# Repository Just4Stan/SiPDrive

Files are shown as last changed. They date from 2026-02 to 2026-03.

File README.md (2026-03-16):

# SiPDrive (Work In Progress, Status: Ordering first hardware)

**Compact Field-Oriented Control (FOC) firmware and hardware for QDD actuators**

SiPDrive is an open-source motor controller built around the STSPIN32G4 System-in-Package, MT6701 magnetic encoder, and CAN-FD communication. It targets compact quasi-direct-drive (QDD) actuator applications with torque, position, and speed control.

<p align="center">
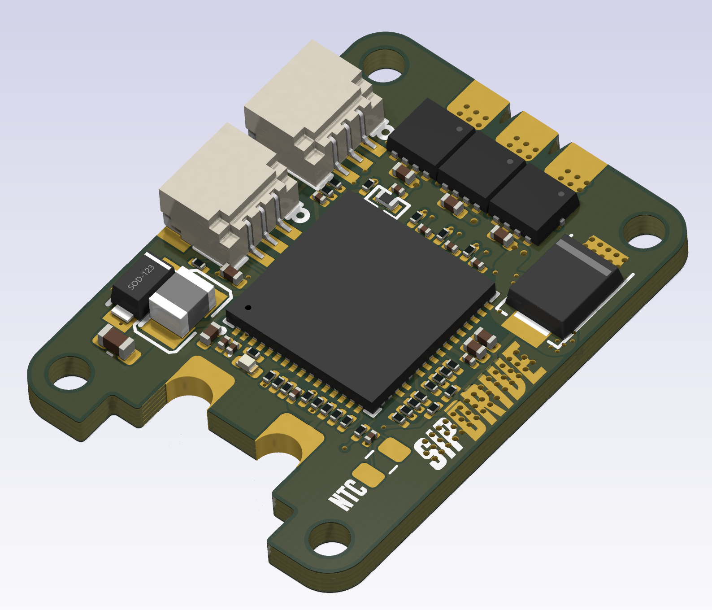
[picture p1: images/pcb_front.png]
SiPDrive PCB front
  
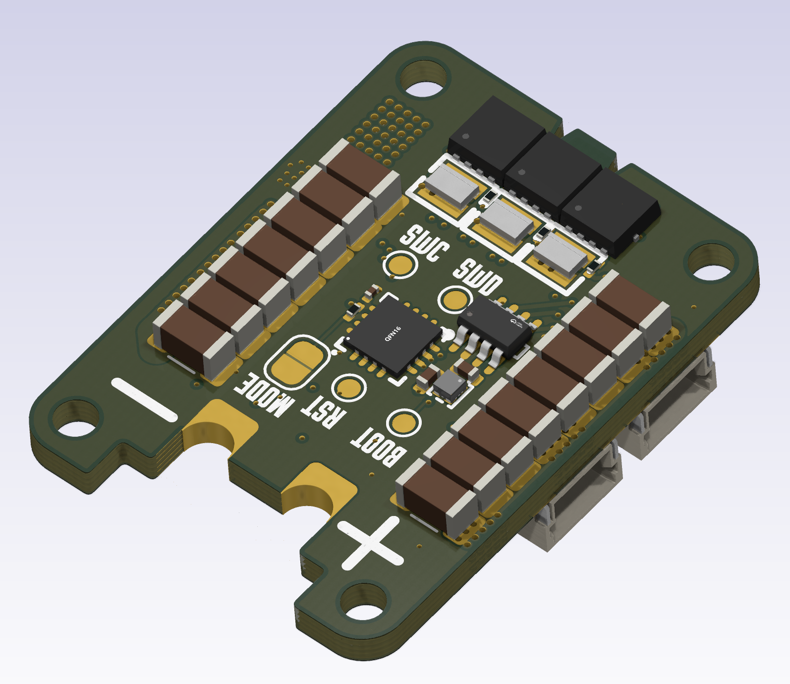
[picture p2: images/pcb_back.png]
SiPDrive PCB back
  
</p>

| | Status |
|---|---|
| **Build** | Compiles (macOS ARM GCC 15.2.0) |
| **Hardware** | PCB designed, ordering assembled from JLCPCB |
| **Firmware** | ~3,100 LOC, 11 KB Flash (8.4%), 13 KB RAM (59%) |
| **License** | CC BY-NC 4.0 |

### Key Features

- 40 kHz FOC current loop with hardware CORDIC acceleration
- CAN-FD command/telemetry (1 Mbps nominal, 5 Mbps data)
- Current and position control modes
- 14-bit magnetic encoder (MT6701 SSI/ABZ selectable via solder jumper)
- On-device encoder calibration with 128-entry compensation table
- Persistent configuration in flash (CRC32 protected)
- Thermal derating and fault protection (board + stator NTC)
- Space Vector PWM (SVPWM) with configurable duty limits

---

## Quick Start

### Prerequisites

```bash
# macOS
brew install arm-none-eabi-gcc cmake
```

### Fetch Dependencies

```bash
cd external
git clone --depth 1 --branch 5.9.0 https://github.com/ARM-software/CMSIS_5.git CMSIS
git clone --depth 1 https://github.com/STMicroelectronics/cmsis_device_g4.git
```

### Build

```bash
cmake -B build \
  -DCMAKE_TOOLCHAIN_FILE=cmake/arm-none-eabi-gcc.cmake \
  -DCMAKE_BUILD_TYPE=Release \
  -DSIPDRIVE_CMSIS_CORE_DIR=external/CMSIS/CMSIS/Core/Include \
  -DSIPDRIVE_STM32G4_DEVICE_DIR=external/cmsis_device_g4

cmake --build build
```

Outputs: `build/SiPDrive.elf`, `.bin`, `.hex`, `.map`

### Flash

```bash
# ST-LINK (recommended)
st-flash write build/SiPDrive.bin 0x08000000

# OpenOCD
openocd -f interface/stlink.cfg -f target/stm32g4x.cfg \
  -c "program build/SiPDrive.elf verify reset exit"
```

---

## Repository Layout

```
SiPDrive/
├── src/                    Firmware source (~3,100 LOC)
├── hw/SiPDrive/            KiCad schematic, PCB, datasheets
├── cmake/                  Toolchain configuration
├── link/                   Linker script (STM32G431)
└── external/               CMSIS dependencies (not vendored)
```

---

<details>
<summary><h2>Hardware Architecture</h2></summary>

### Core Components

**STSPIN32G4 (U1)** - System-in-Package containing:
- STM32G431CBU6 (Cortex-M4F @ 170 MHz)
- Integrated 3-phase gate driver
- Buck converter for MCU power
- 3x operational amplifiers for current sensing
- Memory: 128 KB Flash, 22 KB SRAM + 10 KB CCM RAM

**MT6701 (U2)** - 14-bit magnetic angle sensor
- SSI (default, MODE=HIGH) or ABZ mode (JP1 solder jumper to GND)
- PB7=DO/A, PB6=CLK/B, PB4=CSN/Z

**TCAN1057A (U3)** - CAN-FD transceiver (up to 5 Mbps)

### Pin Assignments

| Peripheral | Function | Pins |
|---|---|---|
| TIM1 | 3-phase PWM (internal to STSPIN32G4 gate driver) | GHS/GLS via 20R gate resistors |
| TIM4 | QEI encoder (ABZ mode) or SPI (SSI mode) | PB7=DO/A, PB6=CLK/B, PB4=CSN/Z |
| OPAMP1 | Phase U current (Ia) | PA1(+), PA3(-), PA2(out) |
| OPAMP2 | Phase W current (Ic) | PA7(+), PC5(-), PA6(out) |
| OPAMP3 | Phase V current (Ib) | PB0(+), PB2(-), PB1(out) |
| ADC1/2 | Vbus, board NTC, stator NTC | PC0 (IN6), PC1 (IN7), PC2 (IN8) |
| FDCAN1 | CAN-FD | PA11=RX, PA12=TX, PA10=TCAN standby |
| I2C3 | STSPIN32G4 gate driver config | Internal SiP bus (no external pins) |
| CORDIC | Hardware sin/cos | - |

### Current Sensing

3-shunt topology with biased differential OPAMPs (EVL reference design):
- **Shunts**: 3x 2 mR (SME08A1FR002T, 0805 1W) on low-side MOSFET sources
- **OPAMP gain**: 10x (Rf=15k / Rin=1.5k), mid-rail bias via 30k/30k divider on OPAMP+ nodes
- **MOSFETs**: 6x CMSA015N06 with 20R gate resistors

### Hardware Constraints

- **128 KB Flash** total - code size must be minimized
- **SCREF overcurrent**: 0.30V threshold via 100k/10k divider (~150A trip with 2 mR shunts)
- **MT6701 MODE**: R6 10k pullup = SSI default, JP1 jumper to GND for ABZ mode
- **Stator NTC (R14)**: DNP solder pad for external thermistor

### KiCad Project

- Schematic: `hw/SiPDrive/SiPDrive.kicad_sch`
- PCB: `hw/SiPDrive/SiPDrive.kicad_pcb`
- Netlist: `hw/SiPDrive/SiPDrive.net`
- Custom libraries: `hw/SiPDrive/kicad/libs/`
- Production outputs: `hw/SiPDrive/production/`

</details>

<details>
<summary><h2>Firmware Architecture</h2></summary>

### Source Layout

| File | Purpose |
|---|---|
| `main.cc` | Main loop, CAN protocol, control loop ISR |
| `config.h` | Compile-time constants |
| `foc_core.{h,cc}` | Clarke/Park transforms, PI current control |
| `position_control.{h,cc}` | Position/velocity PID |
| `calibration.{h,cc}` | Encoder calibration state machine |
| `hal_tim1_pwm.{h,cc}` | TIM1 PWM + 40 kHz ISR |
| `hal_adc_opamp.{h,cc}` | ADC + OPAMP (injected + regular) |
| `hal_qei.{h,cc}` | Quadrature encoder (TIM3/4) |
| `hal_fdcan.{h,cc}` | CAN-FD driver |
| `hal_i2c3_stspin.{h,cc}` | Gate driver I2C config |
| `hal_flash.{h,cc}` | Flash read/write |
| `hal_gpio.{h,cc}` | GPIO utilities |
| `thermal.{h,cc}` | NTC monitoring + derating |
| `persistent_config.{h,cc}` | Flash config (CRC protected) |
| `runtime_support.cc` | Math/string fallbacks (no newlib) |

### Startup Sequence

1. Enable DWT cycle counter
2. Load persistent config from flash (or defaults)
3. Init STSPIN32G4 gate driver via I2C3
4. Init TIM1 PWM (40 kHz) + register ISR
5. Init ADC + OPAMP, calibrate current offsets (1024 samples)
6. Init QEI encoder interface
7. Init FDCAN
8. Apply config (PID gains, thermal limits, calibration)
9. Enable TIM1 and power stage
10. Enter main loop

### Main Loop (~1 kHz)

- Service regular ADC (Vbus, NTC temperatures)
- Update thermal protection
- Handle CAN-FD RX (command frames)
- Run calibration state machine (if active)
- Send telemetry (10 Hz heartbeat)
- Sleep via `__WFI()`

### Control Loop ISR (40 kHz)

1. Check fault conditions (hardware, thermal)
2. Sample encoder position/velocity
3. Read injected ADC (Ia, Ib)
4. Compute Id/Iq command (current mode: direct, position mode: PID cascade)
5. Apply thermal derating
6. FOC pipeline: Clarke -> Park (CORDIC) -> PI controllers -> inverse Park -> SVPWM
7. Update TIM1 duty cycles
8. Queue telemetry if heartbeat due

### HAL Abstraction

All hardware access is through `hal_*` modules. When modifying HAL code, ensure ISR timing is preserved. Use `SIPDRIVE_DEBUG_TIMING=ON` to profile via GPIO.

</details>

<details>
<summary><h2>FOC Algorithm</h2></summary>

Implementation in `foc_core.cc`:

**Clarke Transform** (3-shunt, using Ia and Ib; Ic available for validation):
```
i_alpha = ia
i_beta  = (ia + 2*ib) / sqrt(3)
```

**Park Transform** (using CORDIC hardware, Q1.31 format):
```
id =  cos(theta)*i_alpha + sin(theta)*i_beta
iq = -sin(theta)*i_alpha + cos(theta)*i_beta
```

**PI Current Controllers** (independent Id/Iq):
- Default Kp = 0.30, Ki = 200.0
- Anti-windup: integrator clamped to +/-Vbus/2

**SVPWM**: Common-mode voltage centering, duty range 2%-98%

</details>

<details>
<summary><h2>Control Modes</h2></summary>

### Current Mode (`Mode::kCurrent`)
- Direct Id/Iq control
- 4-byte CAN frame: `[Id_mA, Iq_mA]` (int16 LE)

### Position Mode (`Mode::kPosition`)
- Cascaded PID: position -> velocity -> Iq
- Gains scaled by kp_scale, kd_scale (0.0-1.0)
- 16-byte CAN-FD frame (see protocol section)

</details>

<details>
<summary><h2>CAN-FD Protocol</h2></summary>

### Command Frame (default ID: 0x101)

**4-byte legacy** (current control):

| Byte | Field | Type |
|---|---|---|
| 0-1 | Id | int16 mA, LE |
| 2-3 | Iq | int16 mA, LE |
| 4 | Flags | bit0=clear fault, bit1=start cal |

**16-byte extended** (position/current):

| Byte | Field | Type |
|---|---|---|
| 0-3 | Position | float32 rad, LE (NaN = no position loop) |
| 4-7 | Velocity | float32 rad/s, LE |
| 8-9 | Max torque | int16 mA, LE |
| 10-11 | kp_scale | uint16, 0-32767 maps to 0.0-1.0 |
| 12-13 | kd_scale | uint16, 0-32767 maps to 0.0-1.0 |
| 14 | Flags | same as legacy |
| 15 | Mode | 0=current, 1=position |

### Telemetry Frame (default ID: 0x181, 24 bytes, 10 Hz)

| Byte | Field | Type |
|---|---|---|
| 0-3 | Position | float32 rad, LE |
| 4-7 | Velocity | float32 rad/s, LE |
| 8-9 | Iq measured | int16 mA, LE |
| 10-11 | Id measured | int16 mA, LE |
| 12-13 | Vbus | uint16 mV, LE |
| 14-15 | Board temp | int16, 0.01 C, LE |
| 16-17 | Stator temp | int16, 0.01 C, LE |
| 18 | Fault flags | bit0=gate, bit1=CAN, bit2=thermal |
| 19 | Mode | current mode enum |
| 20-23 | Reserved | - |

</details>

<details>
<summary><h2>Configuration</h2></summary>

### Persistent Configuration

Stored in flash (last page), CRC32 protected, magic `0x4D4D4347`.

Fields: motor pole pairs, current limit, PID gains (position Kp/Ki/Kd, velocity Kp/Ki), velocity limit, thermal thresholds, CAN IDs, encoder calibration (offset + 128-entry table).

### Compile-Time Configuration (`config.h`)

| Parameter | Default | Description |
|---|---|---|
| `SIPDRIVE_SYS_CLOCK_HZ` | 170 MHz | PLL or 16 MHz HSI |
| `SIPDRIVE_CONTROL_LOOP_HZ` | 40000 | Control loop rate |
| `SIPDRIVE_PWM_FREQUENCY_HZ` | 40000 | PWM frequency |
| `SIPDRIVE_TIM1_DEADTIME_NS` | 250 | Gate driver deadtime |
| `SIPDRIVE_ENCODER_CPR` | 16384 | MT6701 14-bit |

### CMake Options

| Option | Default | Description |
|---|---|---|
| `SIPDRIVE_USE_PLL170` | ON | 170 MHz PLL clock |
| `SIPDRIVE_USE_BKIN` | OFF | TIM1 break input (PE15) |
| `SIPDRIVE_DEBUG_TIMING` | OFF | GPIO ISR profiling |

### Adding a New Parameter

1. Add CMake cache variable in `CMakeLists.txt`
2. Add `target_compile_definitions` pass-through
3. Add `#ifndef` fallback + `constexpr` in `config.h`

</details>

<details>
<summary><h2>Encoder Calibration</h2></summary>

Implemented in `calibration.cc`. Compensates encoder non-linearity and determines electrical angle offset.

1. **Forward sweep**: Drive motor with fixed d-axis voltage, sweep electrical angle 0 to 2pi, record encoder error
2. **Reverse sweep**: Repeat in opposite direction to average out cogging torque
3. **Compute table**: 128-entry lookup (encoder angle to correction)
4. **Save to flash**: Electrical offset + compensation table persisted

Trigger calibration via CAN command flag bit 1. Motor must be free to rotate.

</details>

<details>
<summary><h2>Thermal Protection</h2></summary>

Two-level protection per sensor (board NTC, stator NTC):

1. **Warning**: Linear current derating from (fault_temp - margin) to fault_temp
2. **Fault**: Power stage disabled above fault threshold

Defaults: board 120 C fault / 25 C margin, stator 150 C fault / 25 C margin.

NTC thermistors read via ADC at ~1 kHz with piecewise lookup-table interpolation.

</details>

<details>
<summary><h2>Build System Details</h2></summary>

### Toolchain

- ARM GCC 15.2.0 (`arm-none-eabi-gcc`)
- CMake >= 3.20
- Cortex-M4F hard-float configuration

### Dependencies

| Dependency | Location | Source |
|---|---|---|
| CMSIS Core 5.9.0 | `external/CMSIS/` | github.com/ARM-software/CMSIS_5 |
| STM32G4 Device | `external/cmsis_device_g4/` | github.com/STMicroelectronics/cmsis_device_g4 |

### Custom Runtime (`runtime_support.cc`)

Provides `sinf`, `cosf`, `sqrtf`, `fmodf`, `atan2f`, `fabsf`, `memset`, `memcpy`, `memmove`, `memcmp`. Needed because Homebrew ARM toolchain lacks newlib. Uses Taylor series approximations - accuracy ~0.001 for trig functions.

### Memory Layout (linker script: `link/stm32g431vb.ld`)

| Region | Address | Size |
|---|---|---|
| FLASH | 0x08000000 | 128 KB |
| RAM | 0x20000000 | 22 KB |
| CCMRAM | 0x10000000 | 10 KB |

### Current Memory Usage

```
FLASH    11,056 B / 128 KB   8.44%
RAM      13,344 B /  22 KB  59.23%
CCM RAM   8,192 B /  10 KB  80.00%
```

Stack is 4 KB, not yet profiled on hardware.

### Verification

```bash
arm-none-eabi-size -A build/SiPDrive.elf
arm-none-eabi-nm -C -S --size-sort build/SiPDrive.elf
```

### Known Build Issues

1. **FDCAN RXESC/TXESC** registers missing from STM32G431 CMSIS headers (lines commented out in `hal_fdcan.cc`)
2. **Math approximations** - Taylor series trig may need improvement for production
3. **No unit tests** - FOC math validated by inspection only

### Datasheets

Component datasheets are in `hw/SiPDrive/datasheets/`. The STM32G4 reference manual (RM0440, ~37 MB) is gitignored to keep clone size down. Download it directly from [ST](https://www.st.com/resource/en/reference_manual/rm0440-stm32g4-series-advanced-armbased-32bit-mcus-stmicroelectronics.pdf) and place at:
```
hw/SiPDrive/datasheets/rm0440-stm32g4-series-advanced-armbased-32bit-mcus-stmicroelectronics.pdf
```

</details>

<details>
<summary><h2>Bring-Up Workflow</h2></summary>

### Pre-Flight Checklist

- [ ] Motor pole pairs match `config.h` (`kMotorPolePairs = 7`)
- [ ] Encoder CPR correct (`kEncoderCountsPerRev = 16384`)
- [ ] Shunt value correct (`kShuntOhm = 0.002`)
- [ ] OPAMP gain matches hardware (`kOpampGain = 10.0`)
- [ ] Current limits set appropriately
- [ ] Bus voltage safe (`kBusVoltageV = 24.0f`)
- [ ] Thermal limits reviewed

### Step-by-Step

1. **Bench setup**: Current-limited supply, motor free, ST-LINK connected, CAN-FD adapter with 120 ohm termination

2. **Flash**: `st-flash write build/SiPDrive.bin 0x08000000`

3. **CAN-FD host setup**:
   ```bash
   sudo ip link set can0 down
   sudo ip link set can0 type can bitrate 1000000 dbitrate 5000000 fd on
   sudo ip link set can0 up
   ```

4. **Verify telemetry**: `candump can0,181:7FF`

5. **Low-current test** (Id=0, Iq=1000 mA):
   ```bash
   cansend can0 101##10000E803
   ```

6. **Position mode**: Only after current control is validated. Start with small torque limits and low gains.

7. **Calibration**: Set command flag bit 1 in CAN frame.

8. **Validate**: PWM outputs, current polarity, encoder direction, thermal/fault behavior.

### Safety Warnings

- Code is **untested** - expect bugs
- Current sensing polarity is **unknown** until verified
- Electrical angle offset requires **calibration**
- No hardware current limit - **software only**
- Stack usage is **unprofiled**

</details>

<details>
<summary><h2>Schematic Audit (2026-02-14)</h2></summary>

Validated against STSPIN32G4, EVLSPIN32G4-ACT, MT6701, and TCAN1057A datasheets.

**Verdict**: Schematic is ready for PCB layout.

### Current Sensing (validated)

3-shunt biased differential topology matching EVLSPIN32G4-ACT reference:
- 30k/30k bias dividers on OPAMP+ nodes (PA1, PA7, PB0) - provides 1.65V mid-rail DC bias
- 1.5k input resistors from shunt nodes to OPAMP+ inputs
- 15k/1.5k feedback gives 10x differential gain
- 2 mR shunts (SME08A1FR002T, 0805 1W) — full-scale ±82.5A, ~40 mA/LSB resolution

### SCREF Divider (valid)

R15=100k / R37=10k / C30=33n gives VSCREF = 0.300 V. Within STSPIN32G4 valid range (0.2 V to 2.55 V). Estimated trip current ~120 A for 2.5 mohm RDS(on).

### 6S Battery Divider (valid)

R10=100k / R9=10k gives gain 11. At 25.2 V max: Vadc = 2.29 V (within 3.3 V range).

### Inter-IC Validation

| Connection | Status |
|---|---|
| U1 PB7 <-> U2 A (encoder) | Pass |
| U1 PB6 <-> U2 B (encoder) | Pass |
| U1 PB4 <-> U2 Z (encoder) | Pass |
| U2 MODE (strap R6 + JP1) | Pass |
| U1 PA12 -> U3 TXD (CAN) | Pass |
| U1 PA11 <- U3 RXD (CAN) | Pass |
| U1 PA10 -> U3 S (CAN mode) | Pass |

### Remaining Items

1. Clean KiCad ERC warnings (PWR_FLAG hygiene, unused pin markers)
2. Consider adding dedicated VREF+ filtering (ferrite + cap) for improved ADC accuracy in production

</details>

<details>
<summary><h2>Comparison to moteus</h2></summary>

SiPDrive is inspired by [mjbots moteus](https://github.com/mjbots/moteus) but optimized for compactness:

| Feature | moteus | SiPDrive |
|---|---|---|
| MCU | STM32G474 (512K Flash, 128K RAM) | STM32G431 (128K Flash, 32K RAM) |
| Gate Driver | DRV8323 (external) | STSPIN32G4 (integrated SiP) |
| Current Sensing | 3-phase | 3-phase (3x 2 mR shunts, 10x OPAMP) |
| Build System | Bazel + mbed-os | CMake + bare-metal |
| Control Rate | 30 kHz | 40 kHz |
| Communication | CAN-FD + RS485 | CAN-FD only |
| Encoder | AS5047P (SPI) | MT6701 (SSI/ABZ, jumper selectable) |
| Form Factor | Standalone PCB | Compact (motor-mounted) |
| Maturity | Production | Alpha (untested) |
| Binary Size | ~100 KB+ | 11 KB |

### Functional Gaps vs moteus `fw`

SiPDrive is intentionally minimal (~3.7k LOC vs ~21.7k LOC). Key differences:

**Control**: Only current + position modes. Missing: voltage modes, trajectory shaping, torque model, feedforward.

**Protocol**: Fixed CAN frames. Missing: register-based protocol, multiplex server, dynamic config.

**Sensing**: MT6701 SSI/ABZ via jumper. Missing: multi-source position pipeline, AUX port support.

**Safety**: Basic fault flags + thermal. Missing: structured fault codes, timing violation detection, command timeout.

**Testing**: No unit tests or simulation. Missing: host-side protocol tests, regression suite, bootloader.

</details>

<details>
<summary><h2>Roadmap</h2></summary>

### P0: Bring-Up and Controllability
- CAN-FD payload sizing hardening (RXESC/TXESC)
- Host control tooling (Python `python-can` script)
- Safety minimums: UV/OV faults, watchdog (IWDG), fault latching
- Lock MT6701 MODE strategy, validate encoder paths
- Commissioning flow: flash -> telemetry -> low-current spin -> calibration

### P1: Control Quality
- Motor characterization (R, L, electrical direction)
- Loop-rate separation (velocity/position at lower rate)
- Telemetry expansion (electrical angle, duty, loop errors)

### P2: Production-Ready
- Control deadline monitoring
- DMA for regular ADC
- Field weakening, MTPA, optional sensorless estimator

### Future
- CAN bootloader for field updates
- Register-based protocol (moteus compatibility)
- Advanced calibration (multi-turn, temp compensation)
- Host-side unit tests for FOC math and protocol
- Stack profiling and memory optimization

### Known Limitations

- Firmware currently uses only 2 of 3 OPAMP channels (3rd available for validation)
- No hardware overcurrent protection
- PWM frequency not runtime-configurable
- No FOC decoupling (back-EMF, cross-coupling feedforward)
- Taylor series math may be insufficient for high-performance FOC

</details>

<details>
<summary><h2>Debugging and Troubleshooting</h2></summary>

### No Current Sensing
- Check OPAMP config in `hal_adc_opamp.cc`
- Verify ADC injected channels match OPAMP outputs
- Scope OPAMP outputs (should be 0-3.3 V)

### Motor Not Spinning
- Scope TIM1 PWM outputs
- Verify gate driver enabled (`hal_i2c3_stspin.cc`)
- Check fault flags in telemetry
- Verify encoder reads valid position

### Encoder Calibration Fails
- Motor must be free to rotate
- Check ABZ signal connections
- Verify QEI config (`hal_qei.cc`)

### CAN Issues
- Check transceiver wiring and bus termination (120 ohm)
- Verify bitrate: nominal 1 Mbps, data 5 Mbps, FD+BRS
- Debug with `candump can0`

### Debug Tools
- `SIPDRIVE_DEBUG_TIMING=ON`: GPIO toggle on PC14 for ISR profiling
- SWD via ST-LINK + GDB: `arm-none-eabi-gdb build/SiPDrive.elf`
- CAN sniffing: `candump can0`

</details>

<details>
<summary><h2>Code Style</h2></summary>

- **C++17** (configured in CMakeLists.txt)
- Classes: `PascalCase`
- Functions: `PascalCase`
- Variables: `snake_case`
- Constants: `kPascalCase`
- Members: `snake_case_` (trailing underscore)
- Namespaces: `sipdrive::module`
- Headers: `#pragma once`
- ISR code should be inlined; use `__attribute__((hot))` for critical paths

</details>

<details>
<summary><h2>Common Tasks</h2></summary>

### Modifying FOC Gains

Compile-time in `config.h`:
```cpp
constexpr float kIdKp = 0.30f;
constexpr float kIdKi = 200.0f;
constexpr float kIqKp = 0.30f;
constexpr float kIqKi = 200.0f;
```

### Adding a New CAN Command

1. Add handler in `main.cc` `HandleCommandFrame()`
2. Parse frame data with byte helpers (`ReadFloatLe`, etc.)
3. Update global state
4. Document protocol

### Adding a New Fault

1. Add fault flag bit in telemetry definition
2. Implement detection in main loop or ISR
3. Set fault variable (`volatile bool`)
4. In `ControlLoopIsr()`, check and disable power stage
5. Add clear mechanism via CAN command flag

</details>

---

## References

- [STSPIN32G4 Datasheet](hw/SiPDrive/datasheets/stspin32g4.pdf)
- [MT6701 Datasheet](hw/SiPDrive/datasheets/MT6701.pdf)
- [TCAN1057A-Q1 Datasheet](hw/SiPDrive/datasheets/tcan1057a-q1.pdf)
- [STM32G431 Datasheet](hw/SiPDrive/datasheets/stm32g431c6.pdf)
- STM32G4 Reference Manual (RM0440) - [download from ST](https://www.st.com/resource/en/reference_manual/rm0440-stm32g4-series-advanced-armbased-32bit-mcus-stmicroelectronics.pdf) (gitignored, 37 MB)
- FOC Theory: "Vector Control of AC Machines" (Peter Vas)
- SVPWM: ST Application Note AN4013

## License

This project is licensed under [CC BY-NC 4.0](https://creativecommons.org/licenses/by-nc/4.0/) - free for all non-commercial use. See [LICENSE](LICENSE) for details.

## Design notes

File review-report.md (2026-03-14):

# SiPDrive Design Review Report

**Date:** 2026-03-14
**Project:** SiPDrive Motor Controller
**Board Rev:** V1 (first dev board)
**KiCad Version:** 9
**Reviewer:** Claude (automated analysis + datasheet verification)

---

## Executive Summary

The SiPDrive is a compact 3-phase BLDC motor controller based on STSPIN32G4 (System-in-Package with STM32G431 + gate driver + buck/LDO), MT6701 magnetic encoder, TCAN1057A CAN-FD transceiver, and 6× SP40N03GNJ MOSFETs. 8-layer PCB, 33×29mm.

**Verdict: NOT READY FOR ORDER — 3 critical issues must be fixed first.**

### Issue Count

| Severity | Count |
|---|---|
| CRITICAL | 3 |
| HIGH | 7 |
| MEDIUM | 7 |
| LOW | 4 |

---

## Critical Failures (Must Fix Before Ordering)

### CRIT-1: U1 Thermal Pad — Insufficient Vias

**Component:** U1 (STSPIN32G4), pad 65, 4.0×4.0mm exposed pad on GND
**Finding:** Only **1 via** under the thermal pad. Minimum recommended: **9**. Ideal: **16**.
**Impact:** The STSPIN32G4 has Rth_JA = 48.3°C/W. With inadequate thermal vias, heat cannot transfer to inner/back copper planes. The part will overheat under any meaningful motor load, causing thermal shutdown or damage.
**Fix:** Add a 3×3 or 4×4 array of 0.3mm drill vias under the pad. Tent the back side to prevent solder wicking. Standard via pitch: 1.0–1.2mm.

### CRIT-2: DFM Violations — Below JLCPCB Advanced Process Minimums

**Finding:** Two parameters are below even JLCPCB's advanced (6-layer+) process limits:

| Parameter | Actual | JLCPCB Standard | JLCPCB Advanced | Status |
|---|---|---|---|---|
| Track spacing | 0.091mm | 0.127mm | 0.100mm | **FAIL** |
| Annular ring | 0.075mm | 0.125mm | 0.100mm | **FAIL** |

**Impact:** JLCPCB will likely reject the board or require manual review. All 515 vias have 0.075mm annular ring (0.45mm pad, 0.3mm drill).
**Fix:** Either increase via pad to 0.5mm (giving 0.1mm annular ring) or increase to 0.55mm for margin. Review tight spacing areas and increase to ≥0.1mm minimum. Consider using 0.2mm drill vias where space allows.

### CRIT-3: D2 (LED) Extends Past Board Edge

**Component:** D2 (LED, 0402), edge clearance = **-0.03mm**
**Impact:** Component courtyard extends past the board outline. Will either be clipped by board edge or fall off during assembly.
**Fix:** Move D2 inward by at least 0.5mm from board edge.

---

## Phase 1: Schematic Integrity

### 1.1 Power Architecture

**Power tree:**
```
+BATT (10-30V) ──► STSPIN32G4 internal buck (VM pin 61, SW pin 62, L1)
                    ├──► +12V (VCC pin 63, REGIN pin 64)
                    │     ├──► STSPIN32G4 internal LDO
                    │     │     └──► +3.3V (REG3V3 pin 1)
                    │     └──► U4 SK6513SD4-50 LDO
                    │           └──► +5V (U3 VCC)
                    └──► 3-phase bridge (Q1-Q6 via gate driver)
```

| Rail | Voltage | Total Decoupling | Cap Count | Status |
|---|---|---|---|---|
| +BATT | 10-30V | 63.2µF | 10 | PASS |
| +12V | 12V (buck output) | 11.0µF | 2 (C17 1µF, C9 10µF) | PASS |
| +3.3V | 3.3V (internal LDO) | 10.4µF | 5 (C2,C6,C10,C12=100nF, C11=10µF) | PASS |
| +5V | 5V (external LDO) | 1.0µF | 1 (C13 1µF) | **WARN** |

**WARN:** +5V rail has only 1µF (C13). TCAN1057A datasheet recommends 100nF minimum decoupling but with CAN bus transients and 80mA peak current, 1µF is borderline. Consider adding a 100nF close to U3 VCC for HF decoupling.

### 1.2 STSPIN32G4 (U1) Pin Verification

**Power pins:**

| Pin | Name | Net | Expected | Status |
|-----|---|-----|---|---|
| 1 | REG3V3/VDD | +3.3V | 3.3V output | PASS |
| 2 | VBAT | +3.3V | RTC battery/VDD | PASS |
| 26 | VREF+ | +3.3V | ADC reference | PASS |
| 27 | VDDA | __unnamed_15 (via FB1) | Filtered 3.3V | PASS |
| 32 | PGND | GND | Power ground | PASS |
| 61 | VM | +BATT | Battery input | PASS |
| 62 | SW | __unnamed_2 (to L1) | Buck switch | PASS |
| 63 | VCC | +12V | Buck output | PASS |
| 64 | REGIN | +12V | LDO input | PASS |
| 65 | VSS (EPAD) | GND | Thermal pad | PASS |

VDDA is filtered through FB1 (BLM15HD102SN1D ferrite bead) from +3.3V — correct practice for analog supply noise isolation.

**Gate driver pins:**

| Pin | Name | Net | Connects To | Status |
|-----|---|-----|---|---|
| 43 | GHS1 | → R2 (20Ω) | Q1 gate (high-side U) | PASS |
| 29 | GLS1 | → R8 (20Ω) | Q2 gate (low-side U) | PASS |
| 40 | GHS2 | → R3 (20Ω) | Q3 gate (high-side V) | PASS |
| 30 | GLS2 | → R4 (20Ω) | Q4 gate (low-side V) | PASS |
| 37 | GHS3 | → R5 (20Ω) | Q5 gate (high-side W) | PASS |
| 31 | GLS3 | → R7 (20Ω) | Q6 gate (low-side W) | PASS |
| 41 | BOOT1 | C28 (1µF) to PhaseU | Bootstrap U | PASS |
| 38 | BOOT2 | C29 (1µF) to PhaseV | Bootstrap V | PASS |
| 35 | BOOT3 | C27 (1µF) to PhaseW | Bootstrap W | PASS |
| 42 | OUT1 | PhaseU | Phase U output | PASS |
| 39 | OUT2 | PhaseV | Phase V output | PASS |
| 36 | OUT3 | PhaseW | Phase W output | PASS |

Bootstrap caps (C27-C29) = 1µF each, matching EVL reference design. Gate resistors = 20Ω (vs 100Ω in reference). See section 4.1.

**OPAMP & sensing pins:**

| Pin | Name | Net | Function | Status |
|-----|---|-----|---|---|
| 14 | PA1 | OPAMP1_INP | Phase U current sense (+) | PASS |
| 16 | PA3 | OPAMP1_INM | Phase U current sense (−) | PASS |
| 15 | PA2 | OPAMP1_OUT | ADC input (ch13) | PASS |
| 20 | PA7 | OPAMP2_INP | Phase W current sense (+) | PASS |
| 23 | PB0 | OPAMP2_INM | Phase W current sense (−) | PASS |
| 19 | PA6 | OPAMP2_OUT | ADC input (ch16) | PASS |
| 9 | PC0 | VBAT_SENSE | Battery voltage divider | PASS |
| 10 | PC1 | BOARD_NTC | Board temperature | PASS |
| 11 | PC2 | STATOR_NTC | Stator temperature | PASS |
| 52 | SCREF | R15/R37 divider | Overcurrent reference | PASS |

**Communication & debug pins:**

| Pin | Name | Net | Function | Status |
|-----|---|-----|---|---|
| 46 | PA10 | CAN_EN | CAN transceiver enable | PASS |
| 47 | PA11 | CAN_RX | CAN receive | PASS |
| 48 | PA12 | CAN_TX | CAN transmit | PASS |
| 49 | PA13 | SWDIO | SWD data | PASS |
| 50 | PA14 | SWCLK | SWD clock | PASS |
| 8 | PG10 | NRST | Reset | PASS |
| 59 | PB8 | BOOT0 | Boot mode select | PASS |
| 55 | PB4 | ENC_CSN | Encoder chip select | PASS |
| 57 | PB6 | ENC_CLK | Encoder clock (SPI SCK) | PASS |
| 58 | PB7 | ENC_D0 | Encoder data (SPI MISO) | PASS |

**NC pins:** Pins 33, 34 are NC — connected to unnamed nets (floating). Per STSPIN32G4 datasheet, NC pins should be left unconnected. **PASS** (unnamed nets = no connection in KiCad).

**Unused GPIO:** PC3, PC4, PC5, PA0, PA4, PA5, PA8, PA9, PA15, PD2, PB3, PB5, PB9, PB10, PC12, PC13, PC14, PC15, PF0, PF1 — connected to unnamed nets. These are unrouted/unused. Verify no-connect markers are present in schematic. Not a board-killing issue.

### 1.3 MT6701 (U2) Pin Verification

| Pin | Name | Net | Expected | Status |
|-----|---|-----|---|---|
| 1-4 | NC | unnamed | No connect | PASS |
| 5 | PUSH | unnamed | Push button output (unused) | PASS |
| 6 | A/DO | ENC_D0 | SSI data → U1 PB7 | PASS |
| 7 | B/CLK | ENC_CLK | SSI clock → U1 PB6 | PASS |
| 8 | Z/CSN | ENC_CSN | SSI chip select → U1 PB4 | PASS |
| 9-12 | W,NC,U,V | unnamed | UVW outputs (unused) | PASS |
| 13 | VDD | +3.3V | Power (3.0-5.5V range) | PASS |
| 14 | MODE | unnamed | Mode selection | **WARN** |
| 15 | OUT | unnamed | Analog/PWM output (unused) | PASS |
| 16 | GND | GND | Ground | PASS |
| 17 | EP | GND | Exposed pad | PASS |

**WARN (MED-1):** MT6701 MODE pin (pin 14) appears to be on an unnamed net. The MODE pin selects the output interface (SSI/ABZ/UVW/analog). Per datasheet, MODE should be tied to VDD or GND via resistor to select the desired mode. If left floating, mode is undefined. Verify this pin has a pull-up or pull-down in the schematic.

### 1.4 TCAN1057A (U3) Pin Verification

| Pin | Name | Net | Expected | Status |
|-----|---|-----|---|---|
| 1 | TXD | CAN_TX | From U1 PA12 | PASS |
| 2 | GND | GND | Ground | PASS |
| 3 | VCC | +5V | 4.5-5.5V supply | PASS |
| 4 | RXD | CAN_RX | To U1 PA11 | PASS |
| 5 | NC/VIO | +3.3V | See note below | **WARN** |
| 6 | CANL | CAN_L | To connector U5 | PASS |
| 7 | CANH | CAN_H | To connector U5 | PASS |
| 8 | S | CAN_EN | Standby control from U1 PA10 | PASS |

**WARN (HIGH-1): Pin 5 variant ambiguity.** The TCAN1057A (non-V variant) has pin 5 as NC. The TCAN1057A**-V** variant has pin 5 as VIO for I/O level translation. The schematic connects pin 5 to +3.3V, which is correct for the -V variant (enables 3.3V logic levels on TXD/RXD while VCC=5V).

BOM lists LCSC C3236208. **Verify this is the TCAN1057A-V (with VIO), not the plain TCAN1057A.** If it's the non-V variant, connecting voltage to an NC pin is typically harmless (NC pins are internally disconnected) but is not guaranteed safe by the datasheet.

### 1.5 U4 LDO (SK6513SD4-50) Verification

| Pin | Name | Net | Expected | Status |
|-----|---|-----|---|---|
| 1 | OUT | +5V | 5V output | PASS |
| 2 | GND | GND | Ground | PASS |
| 3 | EN | +12V | Enable (tied to input) | PASS |
| 4 | IN | +12V | 12V input | PASS |
| 5 | EP | GND | Thermal pad | PASS |

EN tied to IN = always-on when +12V present. Dropout: 12V→5V = 7V headroom, well within LDO capability. Output capacitor C13 (1µF) present.

**Note:** No datasheet found in datasheets/ directory for SK6513SD4-50. Cannot verify max output current, dropout voltage, or recommended cap values. The "50" suffix likely means 5.0V fixed output.

### 1.6 U5 Connector (SM03B-SRSS-TB)

3-pin JST SH connector. Pin 1 = GND, Pin 2 = CAN_H, Pin 3 = CAN_L, Pins 4-5 = GND (structural).

**WARN (HIGH-2): No ESD/TVS protection on CAN bus lines.** CAN_H and CAN_L go directly from U3 to U5 connector with no TVS diodes. Any ESD event on the connector will hit the TCAN1057A directly. The reference design has a TVS footprint (D3, not mounted). Consider adding a bidirectional TVS (e.g., PESD1CAN) between CAN_H/CAN_L and GND.

### 1.7 SCREF — VDS Monitoring Protection (NOT Current Sense)

**IMPORTANT CORRECTION:** SCREF does NOT compare against the OPAMP current sense output. Per STSPIN32G4 datasheet (page 2, Table 5 page 10): SCREF sets the **VDS monitoring protection threshold**. The gate driver monitors drain-source voltage across each MOSFET while it is on. If VDS exceeds VDSth, it indicates a short-circuit or shoot-through, and all gate outputs are disabled.

**Divider:** R15 (100k) / R37 (10k) from +3.3V to GND, plus internal 400kΩ pull-down on SCREF
**Effective lower R:** 10k ∥ 400k = 9.76kΩ
**SCREF voltage:** 3.3V × 9.76k / (100k + 9.76k) = **0.293V**
**VDSth:** ≈ 0.29V (from Table 5, roughly 1:1 with VSCREF at this range)
**Filter cap:** C30 (33nF) on SCREF net

**VDS trip current** = VDSth / RDS(on) = 0.29V / 0.0029Ω = **~100A**

This is well above the SP40N03GNJ's 75A abs max continuous rating. This is correct — VDS monitoring is a **last-resort hardware protection** for dead shorts and shoot-through events. Normal current limiting is done in firmware via ADC measurements from the OPAMP current sense chain.

**Comparison to reference:** EVL uses SCREF = 1.03V (22k/10k) with STL60N10F7 FETs (RDS(on) = 14.5mΩ): trip at 1.03V / 0.0145Ω ≈ 71A. Same concept — threshold set well above operating range.

| Parameter | SiPDrive | EVL Reference |
|---|---|---|
| SCREF voltage | 0.29V | 1.03V |
| MOSFET RDS(on) | 2.9mΩ | 14.5mΩ |
| VDS trip current | ~100A | ~71A |
| FET abs max ID | 75A | 60A |

**PASS** — VDS protection is appropriately set for short-circuit detection.

**Note:** Overcurrent limiting for normal operation must be implemented in firmware using the OPAMP/ADC current measurements. The VDS monitor will NOT protect against sustained overcurrent below ~100A.

### 1.8 VBAT Sense Divider

**Divider:** R10 (100k) / R9 (10k) from +BATT to GND
**Ratio:** 10k / (100k + 10k) = 0.0909
**Filter cap:** C14 (33nF)

| VBATT | ADC voltage | Status |
|---|---|---|
| 12V | 1.09V | OK |
| 24V | 2.18V | OK |
| 30V | 2.73V | OK (near 3.3V VREF max) |
| 36V | 3.27V | Saturates ADC |

Max measurable voltage before ADC saturation: 3.3V / 0.0909 = **36.3V**. SP40N03GNJ VDS_max = 30V. Divider provides adequate headroom.

**PASS**

### 1.9 OPAMP Current Sense Networks (3 channels)

Each channel uses the STSPIN32G4 internal OPAMPs in differential configuration:

| Component | Value | Function |
|---|---|---|
| R22/R28/R33 | 1.5kΩ | Non-inverting input resistor (from shunt high side) |
| R23/R29/R34 | 1.5kΩ | Inverting input resistor (from shunt low side/GND) |
| R24/R27/R32 | 15kΩ | Feedback resistor (output to inverting input) |
| R25/R26/R30/R31/R35/R36 | 30kΩ | Bias resistors (from +3.3V and to GND) |

**Gain:** 15k / 1.5k = **10 V/V** — matches reference design exactly.
**Bias point:** 30k/30k from +3.3V = **1.65V** midpoint.

Current measurement range:
- Full scale: ±(3.3V/2) / (0.001Ω × 10) = **±165A** (theoretical)
- At 10A: signal = 10 × 0.001 × 10 = 100mV swing from 1.65V
- 12-bit ADC: 3.3V/4096 = 0.806mV/LSB → 10A = 124 LSBs
- Resolution: 165A / 2048 = **0.08A/LSB**

**WARN (HIGH-7): 1mΩ shunts with 10× gain give only 10 mV/A sensitivity.** This is the same sensitivity as moteus r4.11 (0.5mΩ × 20×), which targets 100A+. For a 10-30A class controller, this is poor — 242 mA RMS noise floor, only 124 LSBs at 10A.

**State-of-the-art comparison:**

| Controller | Shunt | Gain | mV/A | Target Current |
|---|---|---|---|---|
| SiPDrive (current) | 1mΩ | 10× | 10 | 10-30A |
| moteus c1 (20A class) | 2mΩ | 20× | 40 | 20A |
| Tinymovr R3.3+ | 2mΩ | 20× | 40 | 30-40A |
| moteus r4.11 (100A+) | 0.5mΩ | 20× | 10 | 100-120A |

Tinymovr specifically switched from 1mΩ to 2mΩ because noise was unacceptable for FOC quality.

**Recommendation:** Change shunts to **2mΩ** (no other schematic changes needed). This doubles resolution to 40.3 mA/LSB, halves noise floor to 121 mA RMS, and gives 248 LSBs at 10A. Full-scale becomes ±82.5A — still well above FET rating. Dissipation at 30A = 1.8W (acceptable in 0805 2W package). Update `config.h`: `shunt_resistance_ohm = 0.002`.

### 1.10 NTC Thermistor Circuits

**Board NTC (R12):** NCP15 (10kΩ at 25°C), 0402 package
- Pull-up: R11 (10kΩ) to +3.3V
- Filter: C15 (33nF)
- ADC: U1 PC1 (BOARD_NTC net)
- At 25°C: V = 3.3 × 10k/(10k+10k) = 1.65V

**Stator NTC (R14):** NCP15 (same part), 0805 package
- Pull-up: R13 (10kΩ) to +3.3V
- Filter: C16 (33nF)
- ADC: U1 PC2 (STATOR_NTC net)

**WARN (MED-3):** R12 (board NTC, 0402) and R14 (stator NTC, 0805) share the same LCSC part C77131. NCP15 series is available in multiple packages, but LCSC C77131 is a specific package. Verify C77131 is available in both 0402 and 0805, or assign different LCSC numbers per package.

### 1.11 Connectivity

- **Unconnected pins:** 0
- **Single-pin nets:** 0
- **Multi-driver nets:** 0
- **ERC warnings:** 2 (both false positives from NTC pin typing)
- **Annotation issues:** None
- **Label warnings:** None

**PASS** — clean connectivity.

---

## Phase 2: PCB Layout

### 2.1 Board Specifications

| Parameter | Value |
|---|---|
| Dimensions | 33.0 × 29.0mm |
| Layer count | 8 |
| Stackup | F.Cu / In1-In6 / B.Cu |
| Total thickness | 1.028mm |
| Min track width | 0.15mm |
| Min spacing | ~0.091mm |
| Via size | 0.45mm pad / 0.3mm drill |
| Via count | 515 |
| Routing complete | Yes (0 unrouted) |

### 2.2 Layer Assignment

| Layer | Primary Usage | GND Fill (mm²) |
|---|---|---|
| F.Cu | Components, signal routing | 497.7 |
| In1.Cu | +BATT zone (161.6mm²) | 689.3 |
| In2.Cu | Signal routing (shunt sense, CAN_EN) | 763.7 |
| In3.Cu | GND plane | 815.3 |
| In4.Cu | Phase output routing, gate signals | 765.9 |
| In5.Cu | +3.3V zone (692.3mm²) | 54.3 |
| In6.Cu | GND plane | 815.3 |
| B.Cu | U2 (MT6701), encoder signals | 775.5 |

**PASS** — good use of inner layers. Dedicated GND planes on In3 and In6 provide solid return paths. +BATT on In1 and +3.3V on In5 are appropriate power distribution.

### 2.3 Power Trace Current Capacity

| Net | Min Width | Max Width | Est. Current (1oz, 10°C rise) | Expected Load | Status |
|-----|---|---|---|---|---|
| +BATT | 0.2mm | 2.0mm | 0.5-5A (trace) + zone | 10-30A peak (motor) | **WARN** |
| GND | 0.16mm | 2.0mm | 0.4-5A (trace) + zones | Same as +BATT | **WARN** |
| +12V | 0.3mm | 0.6mm | 0.7-1.5A | ~200mA (gate driver + LDO) | PASS |
| +3.3V | 0.16mm | 0.4mm | 0.4-1.0A + zone | ~100mA (MCU + encoder) | PASS |
| +5V | 0.5mm | 0.5mm | 1.2A | ~80mA (CAN transceiver) | PASS |
| PhaseU/V/W | 0.15mm | 2.0mm | 0.4-5A (trace) | Motor phase current | **WARN** |

**WARN (MED-4):** +BATT and Phase nets have minimum trace widths of 0.15-0.2mm in sections. These are likely short neck-down segments near pads, not long runs. However, 0.15mm traces can handle only ~0.4A at 10°C rise (IPC-2221, 1oz external). Verify these narrow segments are only pad fanouts, not current-carrying paths. The 2.0mm wide sections and +BATT zone (In1) carry the bulk current — those are adequate.

### 2.4 Via Current Capacity

All vias: 0.3mm drill, 1oz plating (~25µm).
Per-via current capacity: ~0.5A (IPC-2221).

| Net | Via Count | Total Via Current | Expected Current | Status |
|-----|---|---|---|---|
| +BATT | 191 | ~95A | 30A peak | PASS |
| GND | 249 | ~125A | 30A peak | PASS |
| +3.3V | 10 | ~5A | 0.1A | PASS |
| PhaseU | 11 | ~5.5A | Motor current | PASS |
| PhaseV | 10 | ~5A | Motor current | PASS |
| PhaseW | 10 | ~5A | Motor current | PASS |

### 2.5 Zone Summary

| Zone | Net | Layer(s) | Outline (mm²) | Filled (mm²) | Fill Ratio | Status |
|---|-----|---|---|---|---|---|
| GND | GND | All 8 | 1184 | 5177 | 4.37× | PASS |
| +BATT | +BATT | In1.Cu | 208 | 162 | 78% | PASS |
| +3.3V | +3.3V | In5.Cu | 1050 | 692 | 66% | PASS |

### 2.6 Decoupling Placement

| IC | Closest Cap | Distance | Target | Status |
|----|---|---|---|---|
| U1 (STSPIN32G4) | C15 (33nF) | 5.71mm | <2mm | **WARN** |
| U2 (MT6701) | C12 (100nF) | 2.57mm | <3mm | PASS |
| U3 (TCAN1057A) | C13 (1µF) | 2.96mm | <3mm | PASS |
| U4 (LDO) | C17 (1µF) | 1.21mm | <2mm | PASS |

**WARN (HIGH-3):** U1 STSPIN32G4 closest decoupling cap is 5.71mm away. For a gate driver switching at 40kHz with 1A gate current pulses, decoupling should be <1mm from VCC/GND pins. The 14 caps within 10mm provide good total capacitance, but the closest should be tighter. This is mitigated by the 8-layer stackup providing low-impedance power planes, but is still suboptimal.

### 2.7 Placement Density

| Metric | Value |
|---|---|
| Board area | 9.57 cm² |
| Front side | 75 components, 7.9/cm² |
| Back side | 7 components, 0.7/cm² |
| Courtyard overlaps | **49** |

**WARN (HIGH-4): 49 courtyard overlaps.** Largest: R3/R5 (0.372mm²), R1/R20 (0.338mm²), many OPAMP resistor clusters (0.335mm²). This is common on dense motor controller designs and may not cause assembly issues if pad-to-pad clearance is maintained. However, JLCPCB may flag these during DFM review. Verify pick-and-place clearance for the nozzle — 0402 components need ~0.5mm clearance between component bodies.

### 2.8 Tombstoning Risk

**38 components** at medium tombstoning risk (all 0402):
- Boot caps (C1, C4, C5): 5-6× track width asymmetry between thin signal traces and wide phase traces
- GND pour thermal asymmetry: most 0402 caps/resistors with one pad on GND zone
- Zone net asymmetry: components straddling +3.3V or +BATT zones

**WARN (MED-5):** For JLCPCB assembly, 0402 tombstoning is manageable with their reflow profile. The boot cap asymmetry (C1/C4/C5) is the highest risk — consider adding thermal relief or trace stubs to balance the thermal mass. Mark for inspection on first article.

### 2.9 Edge Clearance

| Component | Clearance | Status |
|---|---|---|
| D2 (LED) | -0.03mm | **CRIT-3** (see above) |
| C16 | 0.29mm | WARN |
| R14 | 0.32mm | OK |
| C27 | 0.32mm | OK |

### 2.10 Copper Presence

- U1 (F.Cu): GND zone present on opposite layer (B.Cu). Good thermal path.
- U2 (B.Cu): GND zone present on opposite layer (F.Cu). Good.
- 5 components (C30, R15, R2, R37, TP1) have no opposite-layer copper — acceptable for signal components.

---

## Phase 3: BOM & Sourcing

### 3.1 BOM Summary

| Category | Count | Notes |
|---|---|---|
| Unique parts | 29 | |
| Total components | 83 | |
| DNP | 2 | |
| Missing LCSC # | 2 | R21 (120R), TP1-TP4 (test points) |
| Missing MPN | All | Components use LCSC Part # only, no MPN field |

### 3.2 Part-Specific Issues

| Ref | Value | LCSC | Issue | Severity |
|-----|---|---|---|---|
| R21 | 120Ω (CAN term) | **Missing** | No LCSC part number. Board won't be fully assembled. | HIGH-5 |
| R12 | NCP15 (0402) | C77131 | Same LCSC# as R14 (0805). Different footprints — verify package matches. | MED-3 |
| All | — | — | No MPN field populated. JLCPCB assembly uses LCSC #, so functional but poor traceability. | LOW-1 |
| TP1-4 | Test points | — | No LCSC# needed (bare pads, not assembled). | PASS |

### 3.3 MOSFET Part Number Discrepancy

**HIGH-6:** README.md specifies "CMSA015N06" as the MOSFET, but BOM lists **SP40N03GNJ** (LCSC C22466709). These are completely different parts:
- CMSA015N06: 60V, N-channel (if it exists — could not verify)
- SP40N03GNJ: 30V, 40A, N-channel, PowerPAK 1212-8

The BOM/schematic use SP40N03GNJ. Update README to match. This is a documentation issue, not a hardware issue — but could cause confusion.

### 3.4 Passive Values Cross-Check

| Component | SiPDrive | EVL Reference | Match | Notes |
|---|---|---|---|---|
| Gate resistors | 20Ω | 100Ω | **Different** | See section 4.1 |
| Bootstrap caps | 1µF | 1µF | Match | |
| Shunt resistors | 1mΩ | 20mΩ | **Different** | Different current range |
| OPAMP gain (Rf/Ri) | 15k/1.5k (10×) | 15k/1.5k (10×) | Match | |
| OPAMP bias | 30k | 30k | Match | |
| SCREF divider | 100k/10k (0.3V) | 22k/10k (1.03V) | **Different** | Scaled for 1mΩ shunts |
| NTC pull-up | 10k | 4.7k | **Different** | Different divider ratio, both valid |
| VBUS divider | 100k/10k | 72.3k/3.01k | **Different** | Different voltage range |
| VCC bulk cap | C9 (10µF) | C7 (10µF) | Match | |
| VDDA ferrite | FB1 (BLM15HD) | Not in brief | N/A | Good practice |

### 3.5 Project Settings Anomaly

**LOW-2:** The `.kicad_pro` file contains a netclass pattern for "50Ohm" matching ELRS signal names. This appears to be a leftover from a different project. Custom DRC rule in `.kicad_dru` sets GND zone clearance to 50Ohm nets = 0.300mm. These have no effect unless matching net names exist, but should be cleaned up.

---

## Phase 4: Design-Specific Deep Dives

### 4.1 Gate Drive Analysis

**Gate resistors: 20Ω** (R2-R8, excluding R1 which is a shunt)

The STSPIN32G4 gate driver sources/sinks 1A. With 20Ω gate resistors:
- Peak gate current: VCC / R_gate = 12V / 20Ω = 0.6A (limited by driver, not resistor)
- Gate charge time (est. Qg ≈ 20nC for SP40N03GNJ): τ ≈ Qg × Rg / VCC ≈ 20nC × 20Ω / 12V ≈ 33ns

The EVL reference uses 100Ω gate resistors (120ns switching), which is conservative. 20Ω is more aggressive — faster switching reduces MOSFET losses but increases:
- di/dt noise on gate loops
- EMI from faster voltage transitions
- Ringing on gate signals (especially with long PCB traces)

**WARN (MED-6):** Gate signal traces route through inner layers (In4/In5) with lengths of 13-19mm. Long gate traces with 20Ω drive can ring. If you see gate oscillation or EMI issues, increasing to 33-47Ω is an easy fix. For a first prototype, 20Ω is acceptable to test — just monitor gate waveforms with an oscilloscope.

### 4.2 Current Sense Path

3-shunt topology with low-side sensing:
```
+BATT → Q_high → PhaseX → Motor → PhaseY → Q_low → R_shunt (1mΩ) → GND
                                                     ↓ ↓
                                              OPAMP(+) OPAMP(−)
                                                   ↓
                                              ADC (10× gain)
```

Low-side MOSFET sources (Q2/Q4/Q6) connect to shunt resistors (R1/R19/R20 = 1mΩ, 0805), then to GND. OPAMP non-inverting inputs connect to the high side of each shunt; inverting inputs connect to GND side.

**Shunt power dissipation:** P = I²R = 30² × 0.001 = 0.9W at OCP threshold. 0805 1mΩ resistors are typically rated 0.5-1W. At continuous 20A: P = 0.4W — within rating.

**Layout concern:** Shunt sense traces (Q2-S, Q4-S, Q6-S) route through In2.Cu with lengths of 15-21mm. Kelvin sensing requires traces directly from the shunt pads to the OPAMP inputs, minimizing loop area. Long traces pick up switching noise. Verify these are proper Kelvin connections, not routing through the power path.

### 4.3 Bulk Capacitance

**+BATT rail:**
- 6× 10µF (C1210 ceramic, C18-C23) = 60µF
- 3× 1µF (0402, C27-C29) = 3µF (these are bootstrap, not bulk)
- 1× 220nF (0603, C7) = 0.22µF
- Total ceramic: ~60.2µF

For a 3-phase bridge at 24V, 30A peak:
- Energy per PWM cycle: E = ½ × L × I² (motor dependent)
- Minimum bulk: C > I_peak / (f_sw × ΔV_ripple) = 30 / (40000 × 1) = 750µF for 1V ripple

**WARN (MED-7):** 60µF ceramic is likely insufficient as the sole bulk capacitance for high-current operation. The C1210 10µF ceramics will also derate significantly with DC bias (10µF → ~4-5µF at 24V for X5R/X7R). Effective bulk may be only ~30µF. This is acceptable for a dev board if the motor is powered through an external supply with its own bulk capacitance, but note that standalone operation at high current will have excessive bus voltage ripple.

### 4.4 Bootstrap Circuit

Bootstrap caps: C27, C28, C29 = 1µF each (0402, C1518208)
Bootstrap diodes: Internal to STSPIN32G4

1µF matches the EVL reference design. At 40kHz PWM, the bootstrap caps recharge during the low-side on-time. Minimum bootstrap capacitance:
- Qboot = Qg + I_leak × t_on = 20nC + 100nA × 25µs ≈ 20nC
- C_min = Qboot / ΔV = 20nC / 0.5V = 40nF

1µF provides >25× margin. **PASS**

### 4.5 MCU Configuration Verification

From `src/config.h`:

| Parameter | Value | Notes |
|---|---|---|
| System clock | 170MHz | STM32G431 max | PASS |
| PWM frequency | 40kHz | Standard for BLDC | PASS |
| Control loop | 40kHz | Synchronized with PWM | PASS |
| Dead time | 250ns | Conservative — 10 switching periods at 40kHz | PASS |
| Shunt resistance | 0.001Ω | Matches BOM | PASS |
| OPAMP gain | 10× | Matches resistor network | PASS |
| Bus voltage | 24V nominal | Within SP40N03GNJ range | PASS |
| Encoder CPR | 16384 | MT6701 14-bit = 16384 | PASS |
| Motor pole pairs | 7 | Application-specific | N/A |
| ADC ch. Ia | ch13 (OPAMP1_OUT) | PA2 = ADC1_IN3 or OPAMP1_VOUT | PASS |
| ADC ch. Ib | ch16 (OPAMP2_OUT) | PA6 = ADC2_IN3 or OPAMP2_VOUT | PASS |
| CAN command ID | 0x101 | Application-specific | N/A |
| CAN telemetry ID | 0x181 | Application-specific | N/A |

### 4.6 Debug Interface

- SWDIO (PA13) → TP2 (DIO)
- SWCLK (PA14) → TP1 (CLK)
- NRST (PG10) → TP3 (NRST)
- BOOT0 (PB8) → TP4 (BOOT)

Test points are pad-only (1mm diameter). No series resistors on SWD lines — acceptable for a dev board.

**PASS**

### 4.7 CAN Bus Interface

- TCAN1057A on +5V with CAN_EN from PA10
- TXD/RXD at 3.3V logic (if VIO variant) or 5V-tolerant GPIO
- 120Ω termination resistor (R21) between CAN_H and CAN_L
- JST SH 3-pin connector (U5)

**Note:** CAN_EN trace is 15.36mm long. The S pin (standby) on TCAN1057A is active-low for standby. Connected to PA10 (CAN_EN). Verify firmware drives this pin correctly (high = normal mode, low = standby).

---

## Issue Summary Table

| ID | Severity | Category | Description | Fix Effort |
|----|---|---|---|---|
| CRIT-1 | CRITICAL | PCB | U1 thermal pad: 1 via, needs 9-16 | Add via array |
| CRIT-2 | CRITICAL | DFM | Spacing (0.091mm) and annular ring (0.075mm) below JLCPCB minimums | Increase via pad/spacing |
| CRIT-3 | CRITICAL | PCB | D2 LED extends past board edge | Move component |
| HIGH-1 | HIGH | Schematic | TCAN1057A pin 5 — verify C3236208 is -V variant | Verify part |
| HIGH-2 | HIGH | Schematic | No ESD/TVS on CAN bus connector | Add TVS diode |
| HIGH-3 | HIGH | PCB | U1 decoupling caps too far (5.71mm, need <2mm) | Rearrange layout |
| HIGH-4 | HIGH | PCB | 49 courtyard overlaps — assembly risk | Review placement |
| HIGH-5 | HIGH | BOM | R21 (120Ω CAN term) missing LCSC part number | Assign LCSC # |
| HIGH-6 | HIGH | Documentation | README MOSFET part doesn't match BOM | Update README |
| MED-1 | MEDIUM | Schematic | MT6701 MODE pin (pin 14) — verify pull-up/down | Check schematic |
| HIGH-7 | HIGH | Schematic | 1mΩ shunts with 10× gain = 10 mV/A — too low for 10-30A class. Change to 2mΩ. | Swap BOM entry |
| MED-3 | MEDIUM | BOM | R12 (0402) and R14 (0805) share LCSC C77131 — verify packages | Check LCSC listing |
| MED-4 | MEDIUM | PCB | Power traces neck down to 0.15mm in places | Verify pad fanouts |
| MED-5 | MEDIUM | PCB | 38 components at tombstoning risk (0402s) | Monitor first article |
| MED-5 | MEDIUM | Schematic | 20Ω gate resistors with 13-19mm traces may ring | Test on prototype |
| MED-7 | MEDIUM | Schematic | 60µF bulk cap may be insufficient for standalone high-current use | External bulk or add caps |
| MED-8 | MEDIUM | PCB | Shunt sense traces 15-21mm on In2 — verify Kelvin sensing | Check layout |
| LOW-1 | LOW | BOM | No MPN field on any component | Populate MPNs |
| LOW-2 | LOW | Project | Leftover "50Ohm" netclass from different project | Clean up |
| LOW-3 | LOW | PCB | +5V rail only 1µF decoupling | Add 100nF near U3 |
| LOW-4 | LOW | Schematic | No reverse polarity protection on +BATT | Consider for production |

---

## Positive Findings

- Clean connectivity: 0 unrouted nets, 0 unconnected pins, 0 ERC errors
- 8-layer stackup provides excellent power distribution and signal return paths
- OPAMP gain network exactly matches STSPIN32G4 reference design
- Bootstrap capacitance (1µF) matches reference and has >25× margin
- Proper VDDA filtering with ferrite bead (FB1)
- Adequate via count for power nets (+BATT: 191, GND: 249)
- Bus voltage sensing divider properly scaled for 30V max
- CAN termination resistor included
- NTC temperature monitoring on both board and stator
- Debug interface with all 4 test points (SWD + NRST + BOOT0)

---

## Calculations Appendix

### A1. SCREF / VDS Monitoring Threshold
```
R_lower_eff = R37 || R_SCREF_internal = 10k || 400k = 9.76kΩ
V_SCREF = V_3V3 × R_lower_eff / (R15 + R_lower_eff) = 3.3 × 9.76k / (100k + 9.76k) = 0.293V
VDSth ≈ V_SCREF = 0.293V (from Table 5, ~1:1 at this range)
I_trip = VDSth / RDS(on) = 0.293 / 0.0029 = 101A (short-circuit protection only)
```

### A2. VBAT Sense Divider
```
Ratio = R9 / (R10 + R9) = 10k / (100k + 10k) = 0.0909
V_ADC_max = V_REF / Ratio = 3.3 / 0.0909 = 36.3V
```

### A3. OPAMP Current Sense
```
Gain = R_fb / R_in = 15k / 1.5k = 10 V/V
Bias = V_3V3 × R_lower / (R_upper + R_lower) = 3.3 × 30k / (30k + 30k) = 1.65V
I_fullscale = (V_REF/2) / (R_shunt × Gain) = 1.65 / (0.001 × 10) = 165A
Resolution = I_fullscale / 2048 = 0.0806 A/LSB
```

### A4. NTC Voltage at 25°C
```
V_NTC = V_3V3 × R_NTC / (R_pullup + R_NTC) = 3.3 × 10k / (10k + 10k) = 1.65V
```

### A5. Bootstrap Capacitor Margin
```
Q_required = Q_gate + I_leak × t_on ≈ 20nC + 100nA × 25µs = 20.0025nC
C_min = Q_required / ΔV_max = 20nC / 0.5V = 40nF
C_actual = 1µF → Margin = 1000nF / 40nF = 25×
```

### A6. Gate Drive Timing
```
t_sw ≈ Q_g × R_gate / V_drive = 20nC × 20Ω / 12V ≈ 33ns
Dead time = 250ns → ~7.5× switching time margin (adequate)
```

---

*Generated by automated KiCad analysis with datasheet cross-verification. Manual review of the raw schematic is recommended for items marked WARN or higher.*

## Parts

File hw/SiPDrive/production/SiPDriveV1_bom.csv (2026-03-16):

Designator | Footprint | Quantity | Value | LCSC Part #
C1, C10, C12, C2, C3, C4, C5 | 0201 | 7 | 100n | C181043
C11 | 0402 | 1 | 10uF | C15525
C13, C17 | 0402 | 2 | 1uF | C52923
C14, C15, C16, C30 | 0201 | 4 | 33n | C161475
C18, C19, C20, C21, C24, C25, C26, C32, C33, C34, C35, C36, C37, C6, C8 | 1206 | 15 | 10uF | C5119295
C27, C28, C29 | 0402 | 3 | 1uF | C1518208
C31 | 0402 | 1 | 1uF | C14445
C7 | 0402 | 1 | 220n | C49333232
C9 | 0603 | 1 | 10uF | C96446
D1 | SOD-123_L2.8-W1.8-LS3.7-FD | 1 | DSK110 | C908227
D2 | 0402 | 1 | LED | C20608784
D3 | SMB_L4.5-W3.7-LS5.4-RD | 1 | SMBJ26A_C908802 | C908802
FB1 | 0402 | 1 | BLM15HD102SN1D | C21516
L1 | L1008 | 1 | YSMC252012 | C41405922
Q1, Q2, Q3, Q4, Q5, Q6 | POWERPAK-1212-8_L3.0-W3.0-P0.65-LS3.3-BL | 6 | SP40N03GNJ | C22466709
R1, R19, R21 | R0508 | 3 | SME08A1FR002T | C2692045
R10, R15 | 0201 | 2 | 100k | C270364
R11, R13, R16, R17, R37, R6, R9 | 0201 | 7 | 10k | C473048
R12 | R0402 | 1 | NCP15 | C77131
R14 | 0805 | 1 | NCP15 | C77131
R18, R2, R3, R4, R5, R7, R8 | 0201 | 7 | 20R | C473548
R22, R23, R28, R29, R33, R34 | 0201 | 6 | 1.5k | C270361
R24, R27, R32 | 0201 | 3 | 15k | C473452
R25, R26, R30, R31, R35, R36 | 0201 | 6 | 30k | C246933
TP1 | TestPoint_Pad_D1.0mm | 1 | CLK
TP2 | TestPoint_Pad_D1.0mm | 1 | DIO
TP3 | TestPoint_Pad_D1.0mm | 1 | NRST
TP4 | TestPoint_Pad_D1.0mm | 1 | BOOT
U1 | VFQFPN-64_L9.0-W9.0-P0.50-TL-EP4.0 | 1 | STSPIN32G4 | C7434864
U2 | QFN-16_L3.0-W3.0-P0.50-TL-EP1.7 | 1 | MT6701 | C2913974
U3 | TSOT-23-8_L2.9-W1.6-P0.65-LS2.8-BR | 1 | TCAN1057 | C3236208
U4 | UDFN-4_L1.0-W1.0-P0.65-BL-EP | 1 | LDO | C39673733
U5, U6 | CONN-SMD_SM03B-SRSS-TB-LF-SN-P | 2 | SH-3P | C160403
U7 | SiPDrive_EDGE | 1 | ~

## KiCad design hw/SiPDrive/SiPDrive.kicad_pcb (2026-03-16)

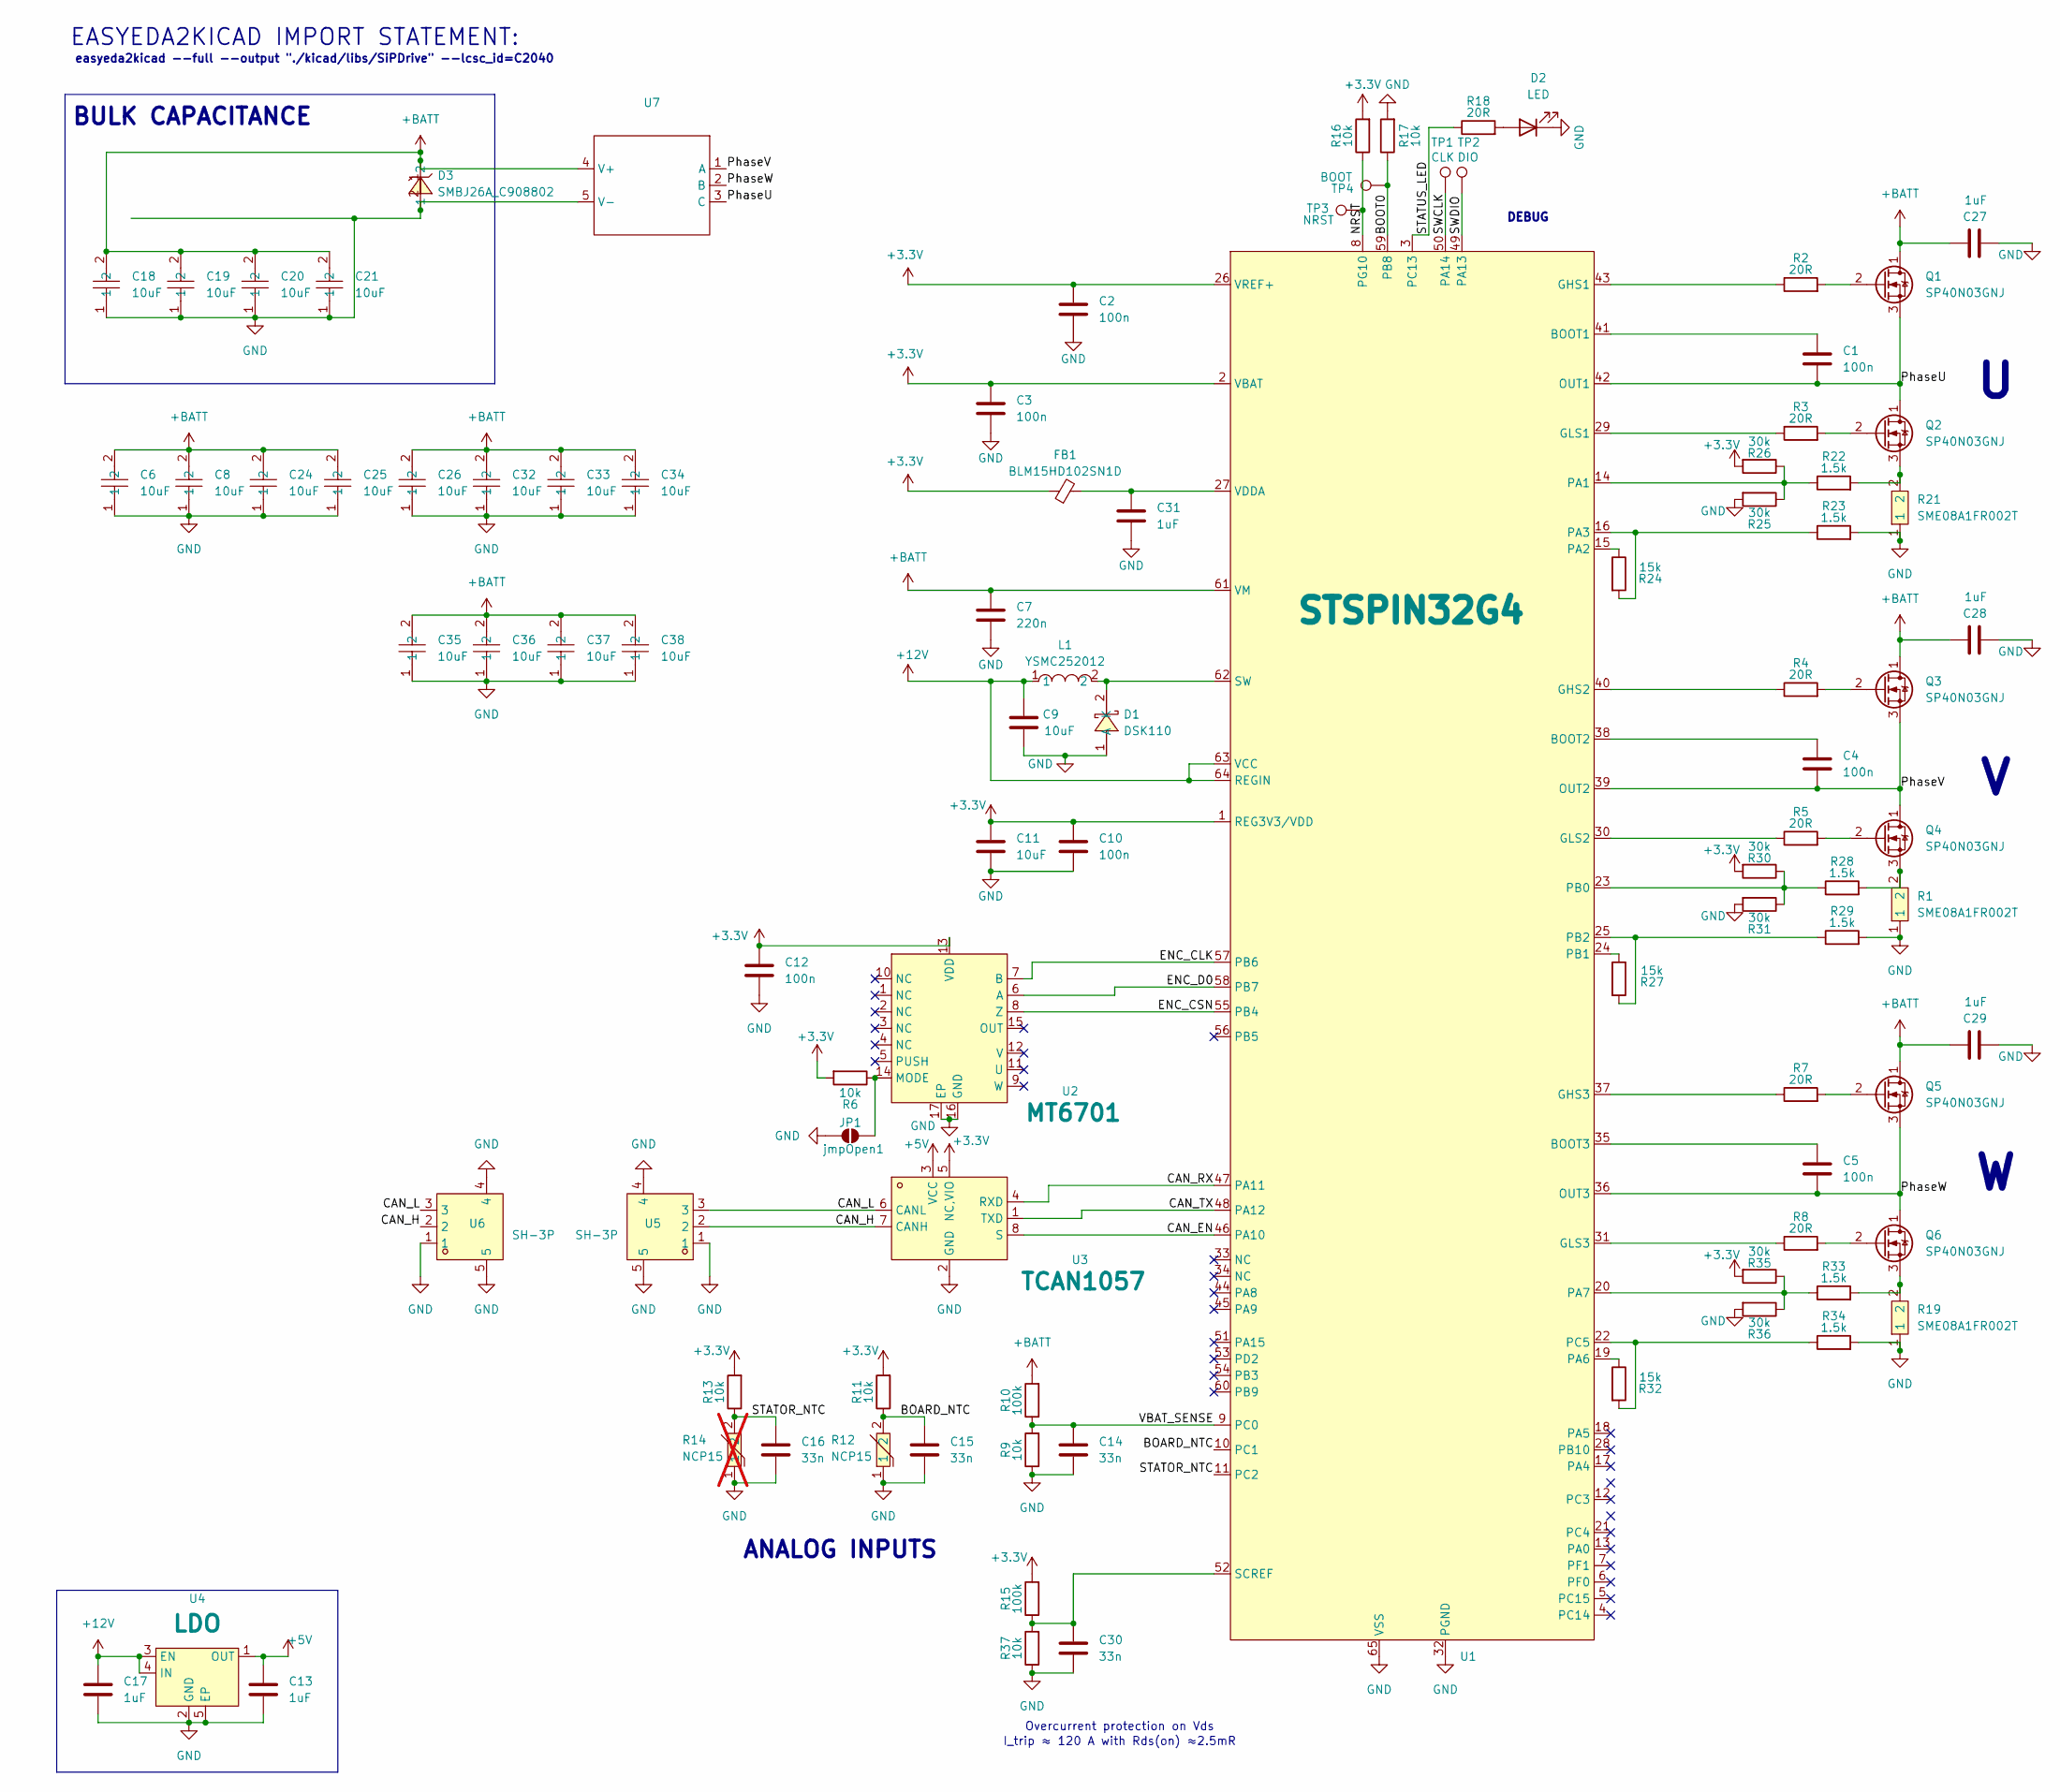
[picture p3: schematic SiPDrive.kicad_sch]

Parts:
C1, C2, C3, C4, C5, C10, C12: 100n; C_0201_0603Metric; LCSC C181043
C6, C8, C18, C19, C20, C21, C24, C25, C26, C32, C33, C34, C35, C36, C37, C38: 10uF; C_1206_3216Metric; LCSC C5119295
C7: 220n; C_0402_1005Metric; LCSC C49333232
C9: 10uF; C_0603_1608Metric; LCSC C96446
C11: 10uF; C_0402_1005Metric; LCSC C15525
C13, C17: 1uF; C_0402_1005Metric; LCSC C52923
C14, C15, C16, C30: 33n; C_0201_0603Metric; LCSC C161475
C27, C28, C29: 1uF; C_0402_1005Metric; LCSC C1518208
C31: 1uF; C_0402_1005Metric; LCSC C14445
D1: DSK110; SOD-123_L2.8-W1.8-LS3.7-FD; LCSC C908227
D2: LED; LED_0402_1005Metric; LCSC C20608784
D3: SMBJ26A_C908802; SMB_L4.5-W3.7-LS5.4-RD; LCSC C908802
FB1: BLM15HD102SN1D; C_0402_1005Metric; LCSC C21516
JP1: jmpOpen1; SolderJumper-2_P1.3mm_Open_RoundedPad1.0x1.5mm
L1: YSMC252012; L1008; LCSC C41405922
Q1, Q2, Q3, Q4, Q5, Q6: SP40N03GNJ; POWERPAK-1212-8_L3.0-W3.0-P0.65-LS3.3-BL; LCSC C22466709
R1, R19, R21: SME08A1FR002T; R0508; LCSC C2692045
R2, R3, R4, R5, R7, R8, R18: 20R; R_0201_0603Metric; LCSC C473548
R6, R9, R11, R13, R16, R17, R37: 10k; R_0201_0603Metric; LCSC C473048
R10, R15: 100k; R_0201_0603Metric; LCSC C270364
R12: NCP15; R0402; LCSC C77131
R14: NCP15; C_0805_2012Metric; LCSC C77131; not fitted
R22, R23, R28, R29, R33, R34: 1.5k; R_0201_0603Metric; LCSC C270361
R24, R27, R32: 15k; R_0201_0603Metric; LCSC C473452
R25, R26, R30, R31, R35, R36: 30k; R_0201_0603Metric; LCSC C246933
TP1: CLK; TestPoint_Pad_D1.0mm
TP2: DIO; TestPoint_Pad_D1.0mm
TP3: NRST; TestPoint_Pad_D1.0mm
TP4: BOOT; TestPoint_Pad_D1.0mm
U1: STSPIN32G4; VFQFPN-64_L9.0-W9.0-P0.50-TL-EP4.0; LCSC C7434864
U2: MT6701; QFN-16_L3.0-W3.0-P0.50-TL-EP1.7; LCSC C2913974
U3: TCAN1057; TSOT-23-8_L2.9-W1.6-P0.65-LS2.8-BR; LCSC C3236208
U4: LDO; UDFN-4_L1.0-W1.0-P0.65-BL-EP; LCSC C39673733
U5, U6: SH-3P; CONN-SMD_SM03B-SRSS-TB-LF-SN-P; LCSC C160403
U7: SiPDrive_EDGE

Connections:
+3.3V: C2.1, C3.1, C10.1, C11.1, C12.1, FB1.1, R6.2, R11.2, R13.2, R15.2, R16.2, R26.2, R30.2, R35.2, U1.1 (REG3V3/VDD), U1.2 (VBAT), U1.26 (VREF+), U2.13 (VDD), U3.5 (NC,VIO)
+5V: C13.1, U3.3 (VCC), U4.1 (OUT)
+12V: C9.1, C17.1, L1.1, U1.63 (VCC), U1.64 (REGIN), U4.3 (EN), U4.4 (IN)
+BATT: C6.2, C7.1, C8.2, C18.2, C19.2, C20.2, C21.2, C24.2, C25.2, C26.2, C27.1, C28.1, C29.1, C32.2, C33.2, C34.2, C35.2, C36.2, C37.2, C38.2, D3.1, Q1.1 (D), Q3.1 (D), Q5.1 (D), R10.2, U1.61 (VM), U7.4 (V+)
/BOARD_NTC: C15.1, R11.1, R12.2, U1.10 (PC1)
/BOOT0: R17.1, TP4.1, U1.59 (PB8)
/CAN_EN: U1.46 (PA10), U3.8 (S)
/CAN_H: U3.7 (CANH), U5.2, U6.2
/CAN_L: U3.6 (CANL), U5.3, U6.3
/CAN_RX: U1.47 (PA11), U3.4 (RXD)
/CAN_TX: U1.48 (PA12), U3.1 (TXD)
/ENC_CLK: U1.57 (PB6), U2.7 (B)
/ENC_CSN: U1.55 (PB4), U2.8 (Z)
/ENC_D0: U1.58 (PB7), U2.6 (A)
/NRST: R16.1, TP3.1, U1.8 (PG10)
/PhaseU: C1.2, Q1.3 (S), Q2.1 (D), U1.42 (OUT1), U7.3 (C)
/PhaseV: C4.2, Q3.3 (S), Q4.1 (D), U1.39 (OUT2), U7.1 (A)
/PhaseW: C5.2, Q5.3 (S), Q6.1 (D), U1.36 (OUT3), U7.2 (B)
/STATOR_NTC: C16.1, R13.1, R14.2, U1.11 (PC2)
/STATUS_LED: R18.1, U1.3 (PC13)
/SWCLK: TP1.1, U1.50 (PA14)
/SWDIO: TP2.1, U1.49 (PA13)
/VBAT_SENSE: C14.1, R9.2, R10.1, U1.9 (PC0)
GND: C2.2, C3.2, C6.1, C7.2, C8.1, C9.2, C10.2, C11.2, C12.2, C13.2, C14.2, C15.2, C16.2, C17.2, C18.1, C19.1, C20.1, C21.1, C24.1, C25.1, C26.1, C27.2, C28.2, C29.2, C30.2, C31.2, C32.1, C33.1, C34.1, C35.1, C36.1, C37.1, C38.1, D1.1 (A), D2.1 (K), D3.2, JP1.1 (A), R1.1, R9.1, R12.1, R14.1, R17.2, R19.1, R21.1, R23.2, R25.2, R29.2, R31.2, R34.2, R36.2, R37.1, U1.32 (PGND), U1.65 (VSS), U2.16 (GND), U2.17 (EP), U3.2 (GND), U4.2 (GND), U4.5 (EP), U5.1, U5.4, U5.5, U6.1, U6.4, U6.5, U7.5 (V-)
unnamed: D1.2 (K), L1.2, U1.62 (SW)
unnamed: D2.2 (A), R18.2
unnamed: JP1.2 (B), R6.1, U2.14 (MODE)
unnamed: Q1.2 (G), R2.2
unnamed: Q2.2 (G), R3.2
unnamed: Q2.3 (S), R21.2, R22.2
unnamed: Q3.2 (G), R4.2
unnamed: Q4.2 (G), R5.2
unnamed: Q4.3 (S), R1.2, R28.2
unnamed: Q5.2 (G), R7.2
unnamed: Q6.2 (G), R8.2
unnamed: Q6.3 (S), R19.2, R33.2
unnamed: C1.1, U1.41 (BOOT1)
unnamed: C4.1, U1.38 (BOOT2)
unnamed: C5.1, U1.35 (BOOT3)
unnamed: R2.1, U1.43 (GHS1)
unnamed: R4.1, U1.40 (GHS2)
unnamed: R7.1, U1.37 (GHS3)
unnamed: R3.1, U1.29 (GLS1)
unnamed: R5.1, U1.30 (GLS2)
unnamed: R8.1, U1.31 (GLS3)
unnamed: R22.1, R25.1, R26.1, U1.14 (PA1)
unnamed: R24.1, U1.15 (PA2)
unnamed: R23.1, R24.2, U1.16 (PA3)
unnamed: R32.1, U1.19 (PA6)
unnamed: R33.1, R35.1, R36.1, U1.20 (PA7)
unnamed: R28.1, R30.1, R31.1, U1.23 (PB0)
unnamed: R27.1, U1.24 (PB1)
unnamed: R27.2, R29.1, U1.25 (PB2)
unnamed: R32.2, R34.1, U1.22 (PC5)
unnamed: C30.1, R15.1, R37.2, U1.52 (SCREF)
unnamed: C31.1, FB1.2, U1.27 (VDDA)

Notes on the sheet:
DEBUG
easyeda2kicad --full --output "./kicad/libs/SiPDrive" --lcsc_id=C2040
I_trip ≈ 120 A with Rds(on) ≈2.5mR
BULK CAPACITANCE
Overcurrent protection on Vds
ANALOG INPUTS
EASYEDA2KICAD IMPORT STATEMENT:

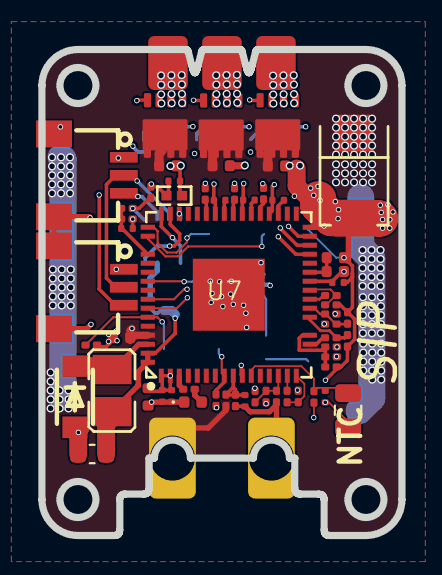
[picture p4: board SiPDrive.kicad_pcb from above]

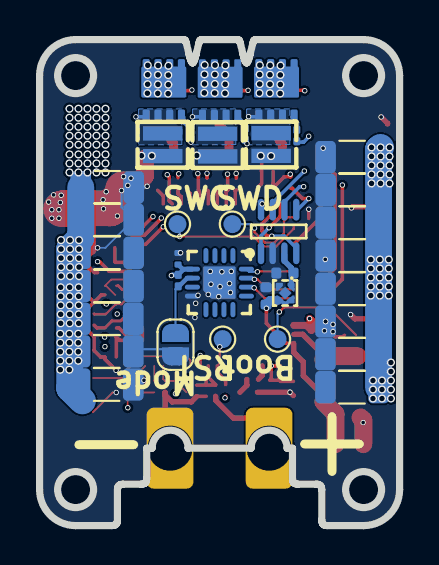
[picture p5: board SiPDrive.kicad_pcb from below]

Board: 6 copper layers, 20.0 x 27.0 mm, 94 parts (36 on the bottom side), 56 nets.

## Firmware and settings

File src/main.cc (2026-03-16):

#include <stddef.h>
#include <stdint.h>

// Define NAN if not available from standard library
#ifndef NAN
#define NAN __builtin_nanf("")
#endif

#include "calibration.h"
#include "config.h"
#include "foc_core.h"
#include "hal_adc_opamp.h"
#include "hal_fdcan.h"
#include "hal_gpio.h"
#include "hal_i2c3_stspin.h"
#include "hal_qei.h"
#include "hal_tim1_pwm.h"
#include "persistent_config.h"
#include "position_control.h"
#include "thermal.h"
#include "stm32g431xx.h"

namespace {

// Command mode: 0=current, 1=position.
enum class Mode : uint8_t {
  kCurrent = 0U,
  kPosition = 1U,
};

// ISR-visible state.
volatile Mode g_mode = Mode::kCurrent;

// Current-mode command (Id/Iq in amps).
volatile sipdrive::foc::FocCommand g_current_cmd = {0.0f, 0.0f};

// Position-mode command.
volatile sipdrive::position_control::PositionCommand g_position_cmd = {
    NAN, 0.0f, 10.0f, 1.0f, 1.0f};

volatile uint32_t g_control_ticks = 0U;
volatile bool g_heartbeat_due = false;
volatile bool g_calibration_requested = false;

sipdrive::foc::FocCore g_foc;
sipdrive::position_control::PositionState g_pos_state = {};
sipdrive::position_control::PositionConfig g_pos_config = {};
sipdrive::persistent_config::PersistentData g_config = {};

// Latest FOC output for telemetry.
volatile float g_iq_meas_a = 0.0f;
volatile float g_id_meas_a = 0.0f;

#if SIPDRIVE_DEBUG_TIMING
GPIO_TypeDef* const kDebugAdcPort = GPIOC;
constexpr uint8_t kDebugAdcPin = 14U;

void InitDebugTiming() {
  sipdrive::hal::gpio::EnablePort(kDebugAdcPort);
  sipdrive::hal::gpio::ConfigureOutput(kDebugAdcPort, kDebugAdcPin, true);
  sipdrive::hal::gpio::Write(kDebugAdcPort, kDebugAdcPin, false);
}

inline void PulseDebugAdcRead() {
  sipdrive::hal::gpio::Write(kDebugAdcPort, kDebugAdcPin, true);
  sipdrive::hal::gpio::Write(kDebugAdcPort, kDebugAdcPin, false);
}
#else
void InitDebugTiming() {}
inline void PulseDebugAdcRead() {}
#endif

// ---- Byte helpers ----

int16_t ReadInt16Le(const uint8_t* data) {
  return static_cast<int16_t>(
      static_cast<uint16_t>(data[0]) |
      (static_cast<uint16_t>(data[1]) << 8U));
}

uint16_t ReadUint16Le(const uint8_t* data) {
  return static_cast<uint16_t>(data[0]) |
         (static_cast<uint16_t>(data[1]) << 8U);
}

float ReadFloatLe(const uint8_t* data) {
  uint32_t u = static_cast<uint32_t>(data[0]) |
               (static_cast<uint32_t>(data[1]) << 8U) |
               (static_cast<uint32_t>(data[2]) << 16U) |
               (static_cast<uint32_t>(data[3]) << 24U);
  float f;
  __builtin_memcpy(&f, &u, sizeof(f));
  return f;
}

void WriteInt16Le(uint8_t* data, int16_t value) {
  const uint16_t u = static_cast<uint16_t>(value);
  data[0] = static_cast<uint8_t>(u & 0xFFU);
  data[1] = static_cast<uint8_t>((u >> 8U) & 0xFFU);
}

void WriteUint16Le(uint8_t* data, uint16_t value) {
  data[0] = static_cast<uint8_t>(value & 0xFFU);
  data[1] = static_cast<uint8_t>((value >> 8U) & 0xFFU);
}

void WriteFloatLe(uint8_t* data, float value) {
  uint32_t u;
  __builtin_memcpy(&u, &value, sizeof(u));
  data[0] = static_cast<uint8_t>(u & 0xFFU);
  data[1] = static_cast<uint8_t>((u >> 8U) & 0xFFU);
  data[2] = static_cast<uint8_t>((u >> 16U) & 0xFFU);
  data[3] = static_cast<uint8_t>((u >> 24U) & 0xFFU);
}

// ---- CAN protocol ----
// Command frame (ID from config, 16 bytes CAN-FD):
//   [0..3]  position (float, LE) — NaN = disable position loop
//   [4..7]  velocity (float, LE)
//   [8..9]  max_torque_mA (int16, LE)
//   [10..11] kp_scale (uint16, 0-32767 → 0.0-1.0)
//   [12..13] kd_scale (uint16, same)
//   [14]    flags: bit0=clear fault, bit1=start calibration
//   [15]    mode: 0=current, 1=position
//
// Legacy 4-byte current-mode is still accepted (bytes 0-1=Id_mA, 2-3=Iq_mA).

void HandleCommandFrame(const sipdrive::hal::fdcan::CanFrame& frame) {
  if (frame.id != g_config.can_command_id) {
    return;
  }

  if (frame.len >= 16U) {
    // Extended position-mode frame.
    const float pos = ReadFloatLe(&frame.data[0]);
    const float vel = ReadFloatLe(&frame.data[4]);
    const int16_t torque_ma = ReadInt16Le(&frame.data[8]);
    const uint16_t kp_raw = ReadUint16Le(&frame.data[10]);
    const uint16_t kd_raw = ReadUint16Le(&frame.data[12]);
    const uint8_t flags = frame.data[14];
    const uint8_t mode_byte = frame.data[15];

    g_position_cmd.position_rad = pos;
    g_position_cmd.velocity_rad_s = vel;
    g_position_cmd.max_torque_a =
        static_cast<float>(torque_ma) * 0.001f;
    g_position_cmd.kp_scale =
        static_cast<float>(kp_raw) * (1.0f / 32767.0f);
    g_position_cmd.kd_scale =
        static_cast<float>(kd_raw) * (1.0f / 32767.0f);

    g_mode = (mode_byte == 1U) ? Mode::kPosition : Mode::kCurrent;

    // When in current mode via 16-byte frame, use velocity fields as Id/Iq.
    if (g_mode == Mode::kCurrent) {
      g_current_cmd.id_a = 0.0f;
      g_current_cmd.iq_a =
          static_cast<float>(torque_ma) * 0.001f;
    }

    if ((flags & 0x01U) != 0U) {
      sipdrive::hal::tim1_pwm::ClearFaultLatch();
      if (!sipdrive::hal::tim1_pwm::FaultActive()) {
        sipdrive::hal::tim1_pwm::EnablePowerStage();
      }
    }
    if ((flags & 0x02U) != 0U) {
      g_calibration_requested = true;
    }
  } else if (frame.len >= 4U) {
    // Legacy 4-byte current-mode frame.
    const int16_t id_milliamps = ReadInt16Le(&frame.data[0]);
    const int16_t iq_milliamps = ReadInt16Le(&frame.data[2]);

    g_current_cmd.id_a = static_cast<float>(id_milliamps) * 0.001f;
    g_current_cmd.iq_a = static_cast<float>(iq_milliamps) * 0.001f;
    g_mode = Mode::kCurrent;

    if (frame.len >= 5U) {
      const uint8_t flags = frame.data[4];
      if ((flags & 0x01U) != 0U) {
        sipdrive::hal::tim1_pwm::ClearFaultLatch();
        if (!sipdrive::hal::tim1_pwm::FaultActive()) {
          sipdrive::hal::tim1_pwm::EnablePowerStage();
        }
      }
      if ((flags & 0x02U) != 0U) {
        g_calibration_requested = true;
      }
    }
  }
}

// Telemetry frame (24 bytes CAN-FD):
//   [0..3]  position (float, LE)
//   [4..7]  velocity (float, LE)
//   [8..9]  iq_measured_mA (int16, LE)
//   [10..11] id_measured_mA (int16, LE)
//   [12..13] vbus_mV (uint16, LE)
//   [14..15] board_temp (int16, 0.01C units)
//   [16..17] stator_temp (int16, 0.01C units)
//   [18]    fault flags: bit0=hw fault, bit1=can fault, bit2=thermal fault,
//                        bit3=calibrating
//   [19]    mode
//   [20..23] reserved

void SendTelemetryFrame() {
  sipdrive::hal::fdcan::CanFrame frame;
  frame.id = g_config.can_telemetry_id;
  frame.len = 24U;
  frame.fd = true;
  frame.brs = true;
  for (uint32_t i = 0; i < sizeof(frame.data); ++i) {
    frame.data[i] = 0U;
  }

  WriteFloatLe(&frame.data[0],
               sipdrive::hal::qei::GetMechanicalAngleRad());
  WriteFloatLe(&frame.data[4],
               sipdrive::hal::qei::GetVelocityRadPerSec());
  WriteInt16Le(&frame.data[8],
               static_cast<int16_t>(g_iq_meas_a * 1000.0f));
  WriteInt16Le(&frame.data[10],
               static_cast<int16_t>(g_id_meas_a * 1000.0f));

  sipdrive::hal::adc_opamp::SlowAnalogSample slow;
  if (sipdrive::hal::adc_opamp::ReadSlowAnalog(&slow)) {
    WriteUint16Le(&frame.data[12],
                  static_cast<uint16_t>(slow.vbat_v * 1000.0f));
  }

  WriteInt16Le(&frame.data[14],
               static_cast<int16_t>(
                   sipdrive::thermal::GetBoardTempC() * 100.0f));
  WriteInt16Le(&frame.data[16],
               static_cast<int16_t>(
                   sipdrive::thermal::GetStatorTempC() * 100.0f));

  uint8_t faults = 0U;
  if (sipdrive::hal::tim1_pwm::FaultActive()) { faults |= 0x01U; }
  if (sipdrive::hal::fdcan::FaultActive()) { faults |= 0x02U; }
  if (sipdrive::thermal::IsFaulted()) { faults |= 0x04U; }
  frame.data[18] = faults;
  frame.data[19] = static_cast<uint8_t>(g_mode);

  (void)sipdrive::hal::fdcan::Send(frame);
}

// ---- Control loop ISR (40 kHz) ----

void ControlLoopIsr() {
  ++g_control_ticks;

  if (sipdrive::hal::tim1_pwm::FaultActive() ||
      sipdrive::thermal::IsFaulted()) {
    sipdrive::hal::tim1_pwm::DisablePowerStage();
    return;
  }

  sipdrive::hal::qei::Sample(sipdrive::config::kControlPeriodSec);

  // Skip FOC when calibration is driving the motor open-loop from main loop.
  if (sipdrive::calibration::IsActive()) {
    return;
  }

  sipdrive::hal::adc_opamp::CurrentSample sample;
  if (!sipdrive::hal::adc_opamp::ReadInjected(&sample)) {
    return;
  }
  PulseDebugAdcRead();

  // Determine Iq command based on mode.
  float id_cmd = 0.0f;
  float iq_cmd = 0.0f;

  const Mode mode = g_mode;
  if (mode == Mode::kPosition) {
    sipdrive::position_control::PositionCommand pos_cmd;
    pos_cmd.position_rad = g_position_cmd.position_rad;
    pos_cmd.velocity_rad_s = g_position_cmd.velocity_rad_s;
    pos_cmd.max_torque_a = g_position_cmd.max_torque_a;
    pos_cmd.kp_scale = g_position_cmd.kp_scale;
    pos_cmd.kd_scale = g_position_cmd.kd_scale;

    iq_cmd = sipdrive::position_control::Update(
        pos_cmd,
        sipdrive::hal::qei::GetMechanicalAngleRad(),
        sipdrive::hal::qei::GetVelocityRadPerSec(),
        sipdrive::config::kControlPeriodSec,
        g_pos_config,
        &g_pos_state);
  } else {
    id_cmd = g_current_cmd.id_a;
    iq_cmd = g_current_cmd.iq_a;
  }

  // Apply thermal derating.
  const float thermal_scale = sipdrive::thermal::GetCurrentScale();
  id_cmd *= thermal_scale;
  iq_cmd *= thermal_scale;

  sipdrive::foc::FocInputs inputs;
  inputs.ia_a = sample.ia_a;
  inputs.ib_a = sample.ib_a;
  inputs.electrical_angle_rad =
      sipdrive::hal::qei::GetElectricalAngleRad();
  inputs.dt_s = sipdrive::config::kControlPeriodSec;

  sipdrive::foc::FocCommand command;
  command.id_a = id_cmd;
  command.iq_a = iq_cmd;

  const sipdrive::foc::FocOutput output = g_foc.Step(inputs, command);
  sipdrive::hal::tim1_pwm::SetDutyCycles(output.duty);

  g_iq_meas_a = output.iq_meas_a;
  g_id_meas_a = output.id_meas_a;

  if ((g_control_ticks % sipdrive::config::kHeartbeatTicks) == 0U) {
    g_heartbeat_due = true;
  }
}

void ApplyConfigFromFlash() {
  // Position/velocity PID.
  g_pos_config.pos_kp = g_config.pos_kp;
  g_pos_config.vel_kp = g_config.vel_kp;
  g_pos_config.vel_ki = g_config.vel_ki;
  g_pos_config.vel_ilimit = g_config.current_limit_a;
  g_pos_config.vel_limit_rad_s = g_config.vel_limit_rad_s;

  // Thermal limits.
  sipdrive::thermal::ThermalConfig tc;
  tc.board_fault_temp_c = g_config.fault_temp_board_c;
  tc.stator_fault_temp_c = g_config.fault_temp_stator_c;
  tc.warning_margin_c = g_config.temp_margin_c;
  sipdrive::thermal::Init(tc);

  // Encoder calibration.
  if (g_config.calib_valid == 0x43414C42U) {
    sipdrive::hal::qei::SetCalibration(
        g_config.calib_elec_offset_rad,
        g_config.calib_table,
        sipdrive::persistent_config::kCalibTableSize);
  }
}

}  // namespace

extern "C" int main(void) {
  CoreDebug->DEMCR |= CoreDebug_DEMCR_TRCENA_Msk;
  DWT->CTRL |= DWT_CTRL_CYCCNTENA_Msk;

  InitDebugTiming();

  // Load persistent config (or defaults if flash is empty/corrupt).
  sipdrive::persistent_config::Load(&g_config);

  // Initialize STSPIN32G4 gate driver via I2C3.
  (void)sipdrive::hal::i2c3_stspin::Init();

  sipdrive::hal::tim1_pwm::Init();
  sipdrive::hal::tim1_pwm::RegisterUpdateCallback(ControlLoopIsr);

  sipdrive::hal::adc_opamp::Init();
  sipdrive::hal::adc_opamp::CalibrateOffsets(
      sipdrive::config::kCurrentOffsetSamples);

  sipdrive::hal::qei::Init();
  sipdrive::hal::fdcan::Init();

  ApplyConfigFromFlash();

  g_foc.Reset();
  sipdrive::position_control::Reset(&g_pos_state);

  sipdrive::hal::tim1_pwm::Start();
  sipdrive::hal::tim1_pwm::EnablePowerStage();

  while (true) {
    const uint32_t control_ticks = g_control_ticks;
    sipdrive::hal::adc_opamp::ServiceRegular(control_ticks);

    // Update thermal protection.
    sipdrive::hal::adc_opamp::SlowAnalogSample slow;
    if (sipdrive::hal::adc_opamp::ReadSlowAnalog(&slow)) {
      sipdrive::thermal::Update(slow.board_ntc_v, slow.stator_ntc_v);
      if (sipdrive::thermal::IsFaulted()) {
        sipdrive::hal::tim1_pwm::DisablePowerStage();
      }
    }

    // Handle incoming CAN frames.
    sipdrive::hal::fdcan::CanFrame frame;
    if (sipdrive::hal::fdcan::Receive(&frame)) {
      HandleCommandFrame(frame);
    }

    // Calibration state machine (runs in main loop, ~1 kHz effective).
    if (g_calibration_requested) {
      g_calibration_requested = false;
      sipdrive::calibration::Start();
    }

    {
      float da = 0.5f, db = 0.5f, dc = 0.5f;
      const auto calib_state =
          sipdrive::calibration::Update(&da, &db, &dc);

      if (calib_state == sipdrive::calibration::State::kForward ||
          calib_state == sipdrive::calibration::State::kReverse) {
        // During calibration, bypass FOC and directly set duty cycles.
        sipdrive::hal::tim1_pwm::DutyCycles duty;
        duty.phase_a = da;
        duty.phase_b = db;
        duty.phase_c = dc;
        sipdrive::hal::tim1_pwm::SetDutyCycles(duty);
      } else if (calib_state == sipdrive::calibration::State::kDone) {
        // Save calibration result to flash.
        const auto& result = sipdrive::calibration::GetResult();
        if (result.valid) {
          g_config.calib_valid = 0x43414C42U;
          g_config.calib_elec_offset_rad = result.electrical_offset_rad;
          for (uint32_t i = 0;
               i < sipdrive::persistent_config::kCalibTableSize; ++i) {
            g_config.calib_table[i] = result.compensation_table[i];
          }
          sipdrive::persistent_config::Save(g_config);

          // Apply immediately.
          sipdrive::hal::qei::SetCalibration(
              g_config.calib_elec_offset_rad,
              g_config.calib_table,
              sipdrive::persistent_config::kCalibTableSize);
        }
      }
    }

    if (g_heartbeat_due) {
      g_heartbeat_due = false;
      SendTelemetryFrame();
    }

    sipdrive::hal::fdcan::Service();
    __WFI();
  }
}

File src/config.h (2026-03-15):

#pragma once

#include <stdint.h>

namespace sipdrive::config {

#ifndef SIPDRIVE_USE_PLL170
#define SIPDRIVE_USE_PLL170 1
#endif

#ifndef SIPDRIVE_SYS_CLOCK_HZ
#if SIPDRIVE_USE_PLL170
#define SIPDRIVE_SYS_CLOCK_HZ 170000000U
#else
#define SIPDRIVE_SYS_CLOCK_HZ 16000000U
#endif
#endif

#ifndef SIPDRIVE_APB2_PRESCALER
#define SIPDRIVE_APB2_PRESCALER 1U
#endif

#ifndef SIPDRIVE_APB1_PRESCALER
#define SIPDRIVE_APB1_PRESCALER 1U
#endif

#ifndef SIPDRIVE_CONTROL_LOOP_HZ
#define SIPDRIVE_CONTROL_LOOP_HZ 40000U
#endif

#ifndef SIPDRIVE_PWM_FREQUENCY_HZ
#define SIPDRIVE_PWM_FREQUENCY_HZ 40000U
#endif

#ifndef SIPDRIVE_TIM1_DEADTIME_NS
#define SIPDRIVE_TIM1_DEADTIME_NS 250U
#endif

#ifndef SIPDRIVE_ADC_SAMPLE_OFFSET_TICKS
#define SIPDRIVE_ADC_SAMPLE_OFFSET_TICKS 0
#endif

#ifndef SIPDRIVE_REGULAR_ADC_RATE_HZ
#define SIPDRIVE_REGULAR_ADC_RATE_HZ 1000U
#endif

// OPAMP1 internal output → ADC1_IN13, OPAMP2 internal output → ADC2_IN16
// (STM32G4 RM0440 Table 76/77, with OPAMPINTEN set).
#ifndef SIPDRIVE_ADC_IA_INJECTED_CHANNEL
#define SIPDRIVE_ADC_IA_INJECTED_CHANNEL 13
#endif

#ifndef SIPDRIVE_ADC_IB_INJECTED_CHANNEL
#define SIPDRIVE_ADC_IB_INJECTED_CHANNEL 16
#endif

#ifndef SIPDRIVE_ENCODER_CPR
#define SIPDRIVE_ENCODER_CPR 16384U
#endif

// MT6701 MODE pin level:
//   0 = ABZ mode on pins 6/7/8
//   1 = SSI/I2C mode on pins 6/7/8
#ifndef SIPDRIVE_MT6701_MODE_HIGH
#define SIPDRIVE_MT6701_MODE_HIGH 1
#endif

#ifndef SIPDRIVE_DEBUG_TIMING
#define SIPDRIVE_DEBUG_TIMING 0
#endif

constexpr uint32_t kSysClockHz = static_cast<uint32_t>(SIPDRIVE_SYS_CLOCK_HZ);

constexpr uint32_t kApb2Prescaler = static_cast<uint32_t>(SIPDRIVE_APB2_PRESCALER);
constexpr uint32_t kApb1Prescaler = static_cast<uint32_t>(SIPDRIVE_APB1_PRESCALER);
constexpr uint32_t kTim1ClockHz =
    (kApb2Prescaler == 1U) ? kSysClockHz : ((kSysClockHz / kApb2Prescaler) * 2U);
constexpr uint32_t kTim3ClockHz =
    (kApb1Prescaler == 1U) ? kSysClockHz : ((kSysClockHz / kApb1Prescaler) * 2U);
constexpr uint32_t kTim4ClockHz = kTim3ClockHz;
constexpr uint32_t kControlLoopHz = static_cast<uint32_t>(SIPDRIVE_CONTROL_LOOP_HZ);
constexpr float kControlPeriodSec = 1.0f / static_cast<float>(kControlLoopHz);

constexpr uint32_t kPwmFrequencyHz = static_cast<uint32_t>(SIPDRIVE_PWM_FREQUENCY_HZ);
constexpr float kDutyMin = 0.02f;
constexpr float kDutyMax = 0.98f;
constexpr uint32_t kTim1DeadtimeNs = static_cast<uint32_t>(SIPDRIVE_TIM1_DEADTIME_NS);
constexpr int32_t kAdcSampleOffsetTicks =
    static_cast<int32_t>(SIPDRIVE_ADC_SAMPLE_OFFSET_TICKS);

constexpr float kBusVoltageV = 24.0f;
constexpr float kShuntOhm = 0.002f;           // SME08A1FR002T (2 milliohm).
constexpr float kOpampGain = 10.0f;            // Differential: Rf/Rin = 15k/1.5k.
constexpr uint8_t kOpampPgaGainBits = 0x04U;   // Not used: OPAMPs run in standalone mode.
constexpr float kAdcReferenceV = 3.3f;
constexpr uint16_t kAdcFullScale = 4095U;
constexpr uint32_t kCurrentOffsetSamples = 1024U;
constexpr uint32_t kRegularAdcRateHz = static_cast<uint32_t>(SIPDRIVE_REGULAR_ADC_RATE_HZ);
constexpr uint32_t kRegularAdcPeriodTicks =
    (kRegularAdcRateHz == 0U) ? 1U : ((kControlLoopHz / kRegularAdcRateHz) > 0U
                                         ? (kControlLoopHz / kRegularAdcRateHz)
                                         : 1U);

// TBD: these must be set from real board routing once OPAMP/ADC paths are finalized.
constexpr int32_t kAdcIaInjectedChannel =
    static_cast<int32_t>(SIPDRIVE_ADC_IA_INJECTED_CHANNEL);
constexpr int32_t kAdcIbInjectedChannel =
    static_cast<int32_t>(SIPDRIVE_ADC_IB_INJECTED_CHANNEL);
constexpr uint32_t kAdcInjectedSampleTimeBits = 4U;  // 47.5 ADC cycles.
constexpr uint32_t kAdcRegularSampleTimeBits = 6U;   // 247.5 ADC cycles.
constexpr uint8_t kAdcVbatChannel = 6U;              // PC0 -> ADC12_IN6 (ADC1 regular).
constexpr uint8_t kAdcBoardNtcChannel = 7U;          // PC1 -> ADC12_IN7.
constexpr uint8_t kAdcStatorNtcChannel = 8U;         // PC2 -> ADC12_IN8.
constexpr float kVbatDividerGain = 11.0f;            // 100k/10k divider -> (Rtop + Rbot) / Rbot.

// Placeholder pending MT6701 ABI configuration and timer x4 decode selection.
constexpr uint32_t kEncoderCountsPerRev = static_cast<uint32_t>(SIPDRIVE_ENCODER_CPR);
constexpr bool kMt6701ModeHigh = (SIPDRIVE_MT6701_MODE_HIGH != 0);
constexpr uint32_t kMotorPolePairs = 7U;

constexpr uint32_t kCanCommandId = 0x101U;
constexpr uint32_t kCanTelemetryId = 0x181U;
constexpr uint32_t kHeartbeatTicks = 4000U;

constexpr float kIdKp = 0.30f;
constexpr float kIdKi = 200.0f;
constexpr float kIqKp = 0.30f;
constexpr float kIqKi = 200.0f;

}  // namespace sipdrive::config

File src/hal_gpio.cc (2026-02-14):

#include "hal_gpio.h"

namespace sipdrive::hal::gpio {
namespace {

void SetPull(GPIO_TypeDef* port, uint8_t pin, Pull pull) {
  const uint32_t shift = static_cast<uint32_t>(pin) * 2U;
  port->PUPDR = (port->PUPDR & ~(0x3UL << shift)) |
                (static_cast<uint32_t>(pull) << shift);
}

}  // namespace

void EnablePort(GPIO_TypeDef* port) {
  if (port == GPIOA) {
    RCC->AHB2ENR |= RCC_AHB2ENR_GPIOAEN;
  } else if (port == GPIOB) {
    RCC->AHB2ENR |= RCC_AHB2ENR_GPIOBEN;
  } else if (port == GPIOC) {
    RCC->AHB2ENR |= RCC_AHB2ENR_GPIOCEN;
  } else if (port == GPIOD) {
    RCC->AHB2ENR |= RCC_AHB2ENR_GPIODEN;
  } else if (port == GPIOE) {
    RCC->AHB2ENR |= RCC_AHB2ENR_GPIOEEN;
  } else if (port == GPIOF) {
    RCC->AHB2ENR |= RCC_AHB2ENR_GPIOFEN;
  }
  (void)RCC->AHB2ENR;
}

void ConfigureInput(GPIO_TypeDef* port, uint8_t pin, Pull pull) {
  const uint32_t shift = static_cast<uint32_t>(pin) * 2U;
  port->MODER &= ~(0x3UL << shift);
  SetPull(port, pin, pull);
}

void ConfigureOutput(GPIO_TypeDef* port, uint8_t pin, bool push_pull) {
  const uint32_t shift = static_cast<uint32_t>(pin) * 2U;
  const uint32_t pin_mask = 1UL << pin;

  port->MODER = (port->MODER & ~(0x3UL << shift)) | (0x1UL << shift);
  if (push_pull) {
    port->OTYPER &= ~pin_mask;
  } else {
    port->OTYPER |= pin_mask;
  }
  port->OSPEEDR = (port->OSPEEDR & ~(0x3UL << shift)) | (0x2UL << shift);
  SetPull(port, pin, Pull::kNone);
}

void ConfigureAlternate(GPIO_TypeDef* port, uint8_t pin, uint8_t af, Pull pull) {
  const uint32_t shift = static_cast<uint32_t>(pin) * 2U;
  const uint32_t afr_idx = pin / 8U;
  const uint32_t afr_shift = (pin % 8U) * 4U;

  port->MODER = (port->MODER & ~(0x3UL << shift)) | (0x2UL << shift);
  port->AFR[afr_idx] = (port->AFR[afr_idx] & ~(0xFUL << afr_shift)) |
                       ((static_cast<uint32_t>(af) & 0xFUL) << afr_shift);
  port->OSPEEDR = (port->OSPEEDR & ~(0x3UL << shift)) | (0x2UL << shift);
  port->OTYPER &= ~(1UL << pin);
  SetPull(port, pin, pull);
}

void ConfigureAnalog(GPIO_TypeDef* port, uint8_t pin) {
  const uint32_t shift = static_cast<uint32_t>(pin) * 2U;
  port->MODER = (port->MODER & ~(0x3UL << shift)) | (0x3UL << shift);
  port->PUPDR &= ~(0x3UL << shift);
}

void Write(GPIO_TypeDef* port, uint8_t pin, bool high) {
  const uint32_t mask = 1UL << pin;
  port->BSRR = high ? mask : (mask << 16U);
}

bool Read(GPIO_TypeDef* port, uint8_t pin) {
  return (port->IDR & (1UL << pin)) != 0U;
}

}  // namespace sipdrive::hal::gpio

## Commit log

2026-02-14 Rebrand and initialize SiPDrive repository
    [SiPDrive.kicad_pcb, SiPDrive.kicad_sch, SiPDriveV1_bom.csv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]
2026-02-14 Prepare repository for GitHub release
    - Add CC BY-NC 4.0 license (non-commercial use)
    - Consolidate all docs (BUILD_NOTES, FW_COMPARISON_REPORT, CLAUDE,
    SCHEMATIC_REWORK) into single README with collapsible sections
    - Remove legacy move_moteus.py (parent repo artifact)
    - Gitignore 37MB STM32G4 reference manual (download link in README)
    - Gitignore KiCad lock files
    - Add EVLSPIN32G4-ACT eval board datasheet
    - Update KiCad schematic and netlist (3-shunt rework in progress)
    - Slim CLAUDE.md to index pointing at README
    [SiPDrive.kicad_sch]
2026-02-16 Updated schematic to a 3 shunt topology and made first deboard PCB layout
    [SiPDrive.kicad_pcb, SiPDrive.kicad_sch, SiPDriveV1_bom.csv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]
2026-02-16 Ordered first dev board and components
    [SiPDrive.kicad_pcb, SiPDrive.kicad_sch]
2026-03-14 other shunts, redo routing
    [SiPDrive.kicad_pcb, SiPDrive.kicad_sch]
2026-03-15 started routing
    [SiPDrive.kicad_pcb, SiPDrive.kicad_sch]
2026-03-16 Final routing, code fixes, production files and BOM
    [SiPDrive.kicad_pcb, SiPDrive.kicad_sch, SiPDriveV1_bom.csv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]
